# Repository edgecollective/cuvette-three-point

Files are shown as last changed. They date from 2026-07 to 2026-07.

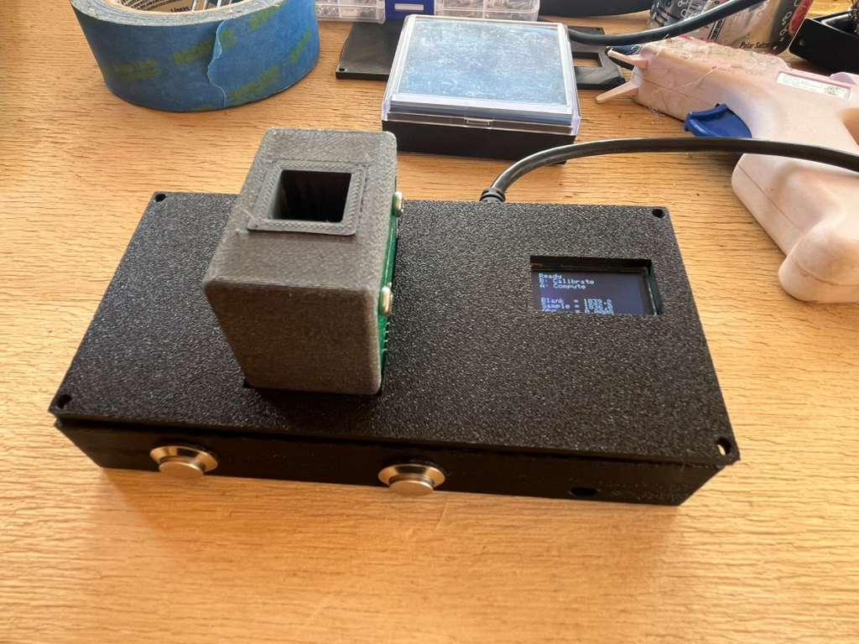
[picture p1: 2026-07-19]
wooden_case/Pasted image.png

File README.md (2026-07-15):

# cuvette-three-point

A 3D-printed cuvette holder for a DIY colorimeter, designed in OpenSCAD.

**Current design: [`v1/holder15.scad`](v1/holder15.scad) — print-tested and
working** (with a ready-to-slice [`v1/holder15.stl`](v1/holder15.stl)). A
standard 12.5 mm square cuvette drops in and seats in the same position
every insertion, with no bi-stability. The earlier `holderN` files in
[`drafts/`](drafts/) are the design history (see
[Design evolution](#design-evolution)).

## How it works: three-point registration

The core idea is kinematic registration. Three vertical rods are printed
half-embedded in the chamber walls — two on one wall (the +x side, flanking
the optical window) and one on the adjacent wall (−y). A printed leaf spring
in the opposite corner presses the cuvette diagonally into all three rods at
once, so the cuvette's position is defined by exactly three line contacts
plus the spring — over-constrained nowhere, repeatable everywhere.

The spring is a flexible tongue that lives inside a fully enclosed pocket in
the corner of the (6 mm thick, opaque) chamber wall:

- **hinged at the bottom**, its root fused into the chamber floor, so it
  prints right side up with no support inside the sealed pocket;
- carrying a **wide flat pressing block** whose face is tangent to the
  cuvette's corner (perpendicular to the corner diagonal). The face is 7 mm
  wide but the corner slit exposes only its dead-flat central ±1.9 mm, so
  the cuvette corner never touches a printed (rounded) edge — this is what
  eliminated the last trace of bi-stability;
- with a **45° wedge slide on top** of the block, so inserting the cuvette
  cams the spring open smoothly, and a steeper (~56°) wedge underneath so
  the block prints cleanly;
- preloaded 0.6 mm: a 12.5 mm cuvette deflects the spring and is held
  against the rods with roughly 2 N.

Because the pocket is internal — sealed by the floor below, solid material
above, and ≥1.6 mm of skin behind and beside it — the spring adds no
ambient-light path into the chamber. Its only opening is the narrow slit
the block presses through.

## Optics and mounting

- 6 mm **optical window** through both ±x walls; the beam passes 15 mm above
  the cuvette's bottom (a standard Z-dimension).
- **PCB mounts** on both ±x faces for 34 × 34 mm emitter and detector boards
  (M3 holes on a 26 mm grid), each board centered on the optical axis,
  recessed inside a light shroud, resting on standoff bosses.
- **Captive hex-nut insets** on each plate's inner face: press an M3 nut in
  once and drive the screws from the board side — no holding nuts in the
  tight gap. (The chamber's corner edges are chamfered so they don't obscure
  the holes.)
- **Base plate** with two ears for screwing the whole assembly to a board.
- The chamber is deliberately shorter than the plates, leaving most of a
  45 mm cuvette exposed to grab.

## Printing

Print **right side up** (base plate on the bed), no support material needed:
the bottom-hinged spring builds base-first inside its pocket, and the only
bridges are the small pocket ceiling and the shrouds' top segments.
Suggested: opaque (ideally black) filament for stray-light rejection.

## Using the OpenSCAD file

Everything is parametric; the interesting knobs are at the top of
`v1/holder15.scad` (`clip_preload` for grip force, `nut_af` for nut fit,
`mount_hole_d` for base screws, etc.). Two view helpers:

- `view_mode = "xray"` — spring drawn solid inside a transparent shell
  (preview/F5 only);
- `view_mode = "cutaway"` — corner carved open to expose the spring
  (real geometry, exportable);
- `show_ghosts = true` — translucent cuvette and PCBs for fit checking.

## Design evolution

Each `holderN.scad` in `drafts/` is self-contained and renderable; changes
were driven by print-and-test cycles:

| file | change |
|---|---|
| holder | original cavity + rods + window concept |
| holder2–3 | corner spring clip; PCB plates; light shrouds |
| holder4–5 | thick walls → fully internal light-tight spring pocket; base plate |
| holder6–7 | consolidated standalone file; optional header cutaways |
| holder8–9 | 15 mm beam height; shortened chamber for grabbing; view modes |
| holder10 | bottom-hinged spring (prints right side up); firmer preload; thicker rods |
| holder11 | flat block face replaces round nub (fixed two stable positions) |
| holder12 | (superseded) wall shave for nut access |
| holder13 | captive hex-nut insets instead |
| holder14 | block raised; steeper under-wedge for cleaner printing |
| **holder15** | **face widened to 7 mm so contact never reaches printed edges — bi-stability gone; print-tested, working** |

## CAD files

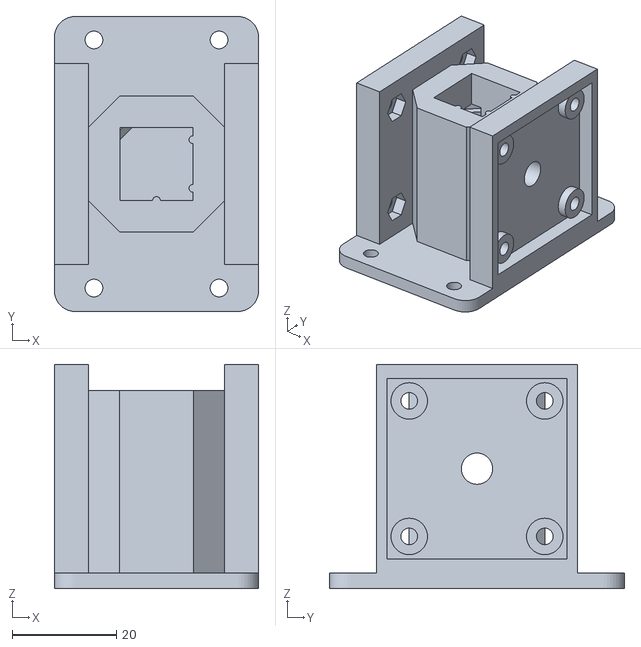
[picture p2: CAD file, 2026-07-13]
drafts/holder15.stl
39.2 x 56.6 x 43.0

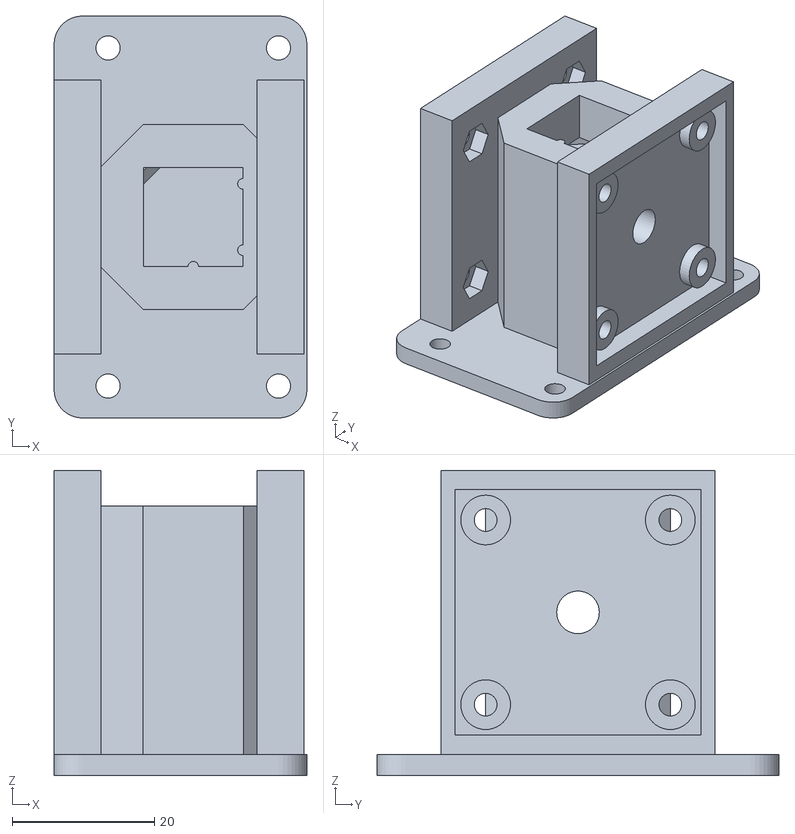
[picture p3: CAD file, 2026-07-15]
v2/holder15_short_one_side.stl
35.6 x 56.6 x 43.0

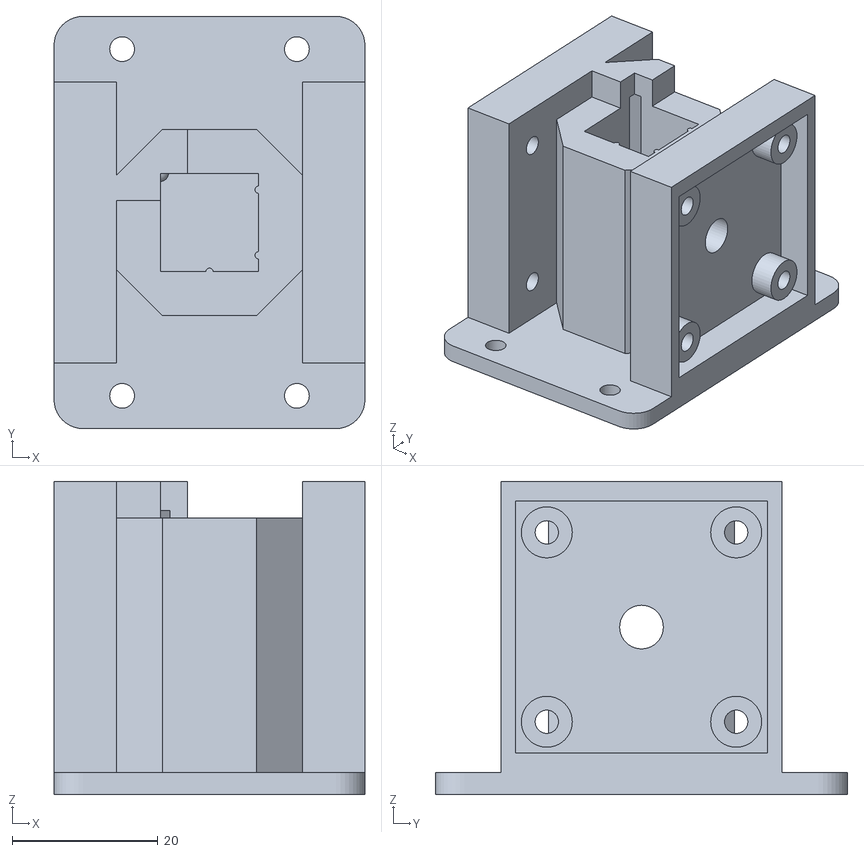
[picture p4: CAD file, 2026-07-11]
drafts/holder9.stl
42.7 x 56.6 x 43.0

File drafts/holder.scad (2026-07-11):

$fn=30;

window_diam = 6;
window_height=15;

cuvette_dim=12.5;
rod_radius=.5;
holder_side=cuvette_dim+rod_radius*2;
holder_depth=40;
wall_width=2;
outer_side=holder_side+wall_width*2;

paddle_width=wall_width;

module holder(){
translate([0,0,holder_depth/2]) {
difference(){
    cube([outer_side,outer_side,holder_depth],center=true);
   
    // inner cavity
    translate([0,0,wall_width]) 
cube([holder_side,holder_side,holder_depth],center=true);
    
    //  optical window
    //translate([outer_side/2,0,0])
rotate([0,90,0])
cylinder(h=holder_side*2,r1=window_diam/2,r2=window_diam/2,center=true);
}



// two points along y on positive x side
translate([cuvette_dim/2+rod_radius,holder_side/3,0])
cylinder(h=holder_depth,r1=rod_radius,r2=rod_radius,center=true);

translate([cuvette_dim/2+rod_radius,-holder_side/3,0])
cylinder(h=holder_depth,r1=rod_radius,r2=rod_radius,center=true);

translate([0,-cuvette_dim/2-rod_radius,0])
cylinder(h=holder_depth,r1=rod_radius,r2=rod_radius,center=true);
}
}

//holder();

/*
rotate(a=10, v=[1,0,0]) {
    translate([outer_side/2,outer_side/2,0])
rotate([0,0,120]) 
    cube([10,3,holder_depth]);  
}
*/

//rotate(a=90,v=[0,0,1]) {
   /* rotate([0,0,90]) {
translate([-holder_side/2,0,0])
cube([paddle_width,holder_side,holder_depth]);
}
*/

difference() {
 
holder();
 
//corner removal    
translate([-holder_side/2,holder_side/2,holder_depth/2])
rotate([0,0,-45]) 
cube([paddle_width,holder_side*2,holder_depth*1.1],center=true);

}
/*
translate([0,0,0]) {
    union() {
        //cube(15, center=true);
        cylinder(h=15,r1=5,r2=5,center=true);
    }
}
*/

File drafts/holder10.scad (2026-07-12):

// holder10.scad -- holder9 with a bottom-hinged spring and a bigger nub,
// printable RIGHT SIDE UP.
//
// New in holder10 (from print testing of holder9 -- cuvette sat too loose):
//   - the tongue is flipped: hinged at the BOTTOM (root fused into the
//     chamber floor), free end at the top.  Printed right side up it builds
//     base-first with no support in its sealed pocket, so the whole part now
//     prints in its natural orientation: base plate and ears on the bed,
//     nothing to support.  The clip anchor tower is gone (no longer needed);
//     the spring arm is the same length as before (root z=5, nub z=20);
//   - grip firmed up: nub radius 1.2 -> 2.0 (a fatter, more surely-printed
//     bump with a gentler insertion ramp) and clip_preload 0.4 -> 0.6, so
//     the constrained square is ~12.08 mm -- a 12.5 mm cuvette deflects the
//     spring 0.6 mm and is pressed into the rods at ~2 N.  The pocket got
//     correspondingly deeper (pocket_back 12.6, slit front 8.3) to keep
//     ~2x spring-back travel and clearance around the fatter nub;
//   - rod_radius 0.5 -> 0.75: sturdier printed registration rods (their
//     contact surfaces stay exactly on the cuvette envelope).
//
// From holder9: set view_mode (just below) to choose how the model is
// shown:
//   "solid"   -- the real, printable part (default; use this for STL export)
//   "xray"    -- the tongue and nub drawn solid, everything else as a
//                transparent ghost, so the clip is visible in place
//   "cutaway" -- the chamber wall around the clip corner is carved away,
//                leaving the whole tongue (crimson) standing exposed in
//                the opening
// The xray ghosts use the % modifier, so they vanish on render (F6) --
// preview with F5.  The cutaway DOES render/export, handy for a demo print.
//
// From holder8:
//   - the chamber tops out at chamber_depth (the PCB plates and shrouds
//     keep their full height -- the 34 mm boards require it), so most of a
//     45 mm cuvette stands exposed for grabbing;
//   - floor_thick 5: the beam passes 15 mm above the cuvette's bottom
//     (standard Z-dimension); the nub presses at the same height.
//
// From holder7: each shroud can get a slot through one lateral (+/-y)
// side wall for the PCB's bottom-edge pin header.  Install the board
// rotated 90 degrees (the symmetric 26 mm hole grid allows it) so the
// header edge faces the slot; a right-angle header's pins then point out
// sideways -- parallel to the base plate, perpendicular to the cuvette
// axis.  The slot is open toward the shroud rim, so a board with the
// header already soldered drops straight into its pocket.  Toggle per side
// with header_cutaway_det / header_cutaway_emit; both slots sit on the same
// global y side (header_side) so the wiring exits together.
//
// Cuvette holder for a colorimeter, in one self-contained file:
//   - square cavity with three registration rods (two on +x, one on -y) and
//     a 6 mm optical window through the +/-x walls at half height;
//   - a springy corner clip: a flexible tongue anchored at the top, living
//     in a fully INTERNAL light-tight pocket at the -x/+y corner, whose
//     rounded nub presses the cuvette diagonally into the rods -- same
//     seat every insertion, no ambient light path into the chamber;
//   - thick (6 mm) opaque walls, with the four vertical corner edges
//     chamfered so they don't obscure the PCB mounting holes;
//   - shrouded mounting plates on +/-x for the emitter and detector PCBs
//     (34 mm square, M3 holes on a 26 mm grid), boards recessed behind a
//     light-blocking rim, screws self-tap into 2.5 mm pilot holes;
//   - a base plate with two ears (+/-y) for screwing the whole assembly
//     to a board.
//
// PRINT RIGHT SIDE UP (base plate on the bed).  The bottom-hinged tongue
// builds base-first from the chamber floor, its sealed pocket needs no
// support (the pocket ceiling is a ~4 mm internal bridge), and everything
// else rises from the base -- no support material anywhere.  The only real
// bridge is each shroud's top segment (~35 mm), which prints acceptably.

$fn = 40;

view_mode   = "solid"; // "solid" | "xray" | "cutaway"
show_ghosts = false;    // translucent cuvette + PCBs for fit checking

/* ---- cuvette chamber ---- */
window_diam  = 6;
cuvette_dim  = 12.5;
rod_radius   = 0.75;  // sturdier printed rods; contact stays on the envelope
holder_side  = cuvette_dim + rod_radius*2;
holder_depth = 40;
wall_width   = 6;    // thick: makes the clip pocket internal, walls opaque
floor_thick  = 5;    // cuvette seat height; beam = window_z - floor_thick
                     // = 15 mm above the cuvette bottom
chamber_depth = 35;  // chamber wall height (holder_depth stays the height
                     // of the PCB plates/shrouds)
outer_side   = holder_side + wall_width*2;
window_z     = holder_depth/2;   // optical window height

/* ---- spring clip ---- */
clip_thick   = 1.6;   // tongue thickness
clip_width   = 5;     // tongue width across the corner
clip_gap     = 0.7;   // clearance from tongue face to seated cuvette corner
clip_preload = 0.6;   // nub interference with the seated cuvette corner
clip_tip_z   = 25;    // height of the tongue's FREE END (top; hinge is at
                      // the bottom, fused into the chamber floor at z=5)
nub_r        = 2.0;   // fat nub: prints reliably, gentle insertion ramp
nub_len      = 3;
nub_z        = window_z;  // nub presses at optical-path height

/* ---- internal clip pocket (diagonal distances from cavity center) ---- */
pocket_front = 8.3;   // front plane; breaks the cavity corner into a slit
                      // (deepened so the r=2 nub clears the slit edges)
pocket_back  = 12.6;  // back plane; deep enough for ~2x preload travel
pocket_hw    = 3.7;   // half-width; 1.2 mm side gap around the tongue
pocket_skin  = 1.6;   // opaque skin kept behind the pocket at the corner
pocket_top   = 27;    // pocket ceiling; solid corner above seals it

// the body's vertical corner edges are chamfered back to this diagonal
// distance: clears the PCB bosses/pilot holes (at y=+/-13) that the full
// square corners would obscure, while keeping the clip pocket sealed
corner_flat_d = pocket_back + pocket_skin;

d_cuvette = cuvette_dim/2 * sqrt(2);   // seated cuvette corner edge (~8.84)
d_face    = d_cuvette + clip_gap;      // inner face of the tongue
d_nub_tip = d_cuvette - clip_preload;  // nub tip, past the cuvette corner

/* ---- PCB mounts ---- */
pcb_size     = 34;
hole_spacing = 26;
pcb_thick    = 1.6;
m3_pilot     = 3.2;
boss_d       = 7;
standoff     = 2;
plate_thick  = 3;
shroud_wall  = 2;
pcb_clr      = 0.3;
shroud_lip   = 0;
shroud_in    = pcb_size + 2*pcb_clr;
shroud_out   = shroud_in + 2*shroud_wall;
shroud_h     = standoff + pcb_thick + shroud_lip;
plate_width  = shroud_out;

/* ---- optional header cutaways ---- */
header_cutaway_det  = false;   // slot in the detector-side shroud
header_cutaway_emit = false;   // slot in the emitter-side shroud
header_side  = 1;     // +1: slot on the +y side, -1: on the -y side
header_len   = 22;    // slot length along z (7x2.54 header body + margin)
header_clear = 3;     // slot floor this far below the board's inner face,
                      // clearing a right-angle header body on that side

/* ---- base plate ---- */
base_thick   = 3;
ear_deep     = 9;     // how far the ears extend past the plates in y
base_r       = 4;     // corner radius
mount_hole_d = 3.4;   // M3 clearance; 4.2 for #6 wood screws
base_x       = 2*(outer_side/2 + plate_thick + shroud_h);  // flush w/ shrouds
base_y       = plate_width + 2*ear_deep;
mount_hole_x = 12;                              // holes at (+/-x, +/-y)
mount_hole_y = plate_width/2 + ear_deep/2;

// place children at diagonal distance d up the -x/+y corner;
// local +x points back toward the cavity center, local y along the corner
module at_corner(d=0, z=0) {
    translate([-d/sqrt(2), d/sqrt(2), z])
        rotate([0,0,-45])
            children();
}

/* ---------- chamber body (chamber_depth tall) ---------- */
module body() {
    difference() {
        // chamber walls
        translate([-outer_side/2, -outer_side/2, 0])
            cube([outer_side, outer_side, chamber_depth]);

        // inner cavity
        translate([-holder_side/2, -holder_side/2, floor_thick])
            cube([holder_side, holder_side, holder_depth]);

        // optical window
        translate([0, 0, window_z])
            rotate([0,90,0])
                cylinder(h=outer_side+2, r=window_diam/2, center=true);
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

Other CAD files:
drafts/holder14.stl
drafts/holder10.stl
drafts/holder11.scad
drafts/holder12.scad
drafts/holder13.scad
drafts/holder14.scad
drafts/holder15.scad
drafts/holder2.scad
drafts/holder2_mounted.scad
drafts/holder3.scad
drafts/holder4.scad
drafts/holder5.scad
drafts/holder6.scad
drafts/holder6_a.scad
drafts/holder7.scad
drafts/holder8.scad
drafts/holder9.scad
v1/holder15.scad
v2/holder15_short_one_side.scad
v2/holder16.scad
wooden_case/v1/case1.scad
wooden_case/v2/case2.scad
wooden_case/v3/case3.scad
wooden_case/v3_shorter/case3_shorter.scad
wooden_case/v4/case4.scad
wooden_case/v4/post4.scad
wooden_case/v5/case5.scad

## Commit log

2026-07-12 Add CLAUDE.md: design rationale, print requirements, verification recipes
2026-07-12 holder7: sync latest parameter tweaks (standoff 3, no shroud lip, header cutaways off)
    [holder7.scad]
2026-07-12 spring flip
    [holder10.scad, holder10.stl]
2026-07-13 README: document the working holder15 design; export blessed holder15.stl
    [holder15.stl]
2026-07-15 Reorganize: blessed v1/ (holder15) + drafts/ for the design history; update docs
    [holder.scad, holder10.scad, holder10.stl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]
